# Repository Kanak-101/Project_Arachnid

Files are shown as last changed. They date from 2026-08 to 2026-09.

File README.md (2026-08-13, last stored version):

In development Phase

# Setting up your Laptop (Windows 11)

First connect the bot with your laptop via ethernet.

1. Open PowerShell in administrative mode and run `Get-NetAdapter` to list the connections.
2. Find the one that's your bot's Ethernet. Replace `Ethernet` with your Ethernet name in the following commands. And then run this commands:
```
Remove-NetIPAddress -InterfaceAlias "Ethernet" -Confirm:$false
New-NetIPAddress -InterfaceAlias "Ethernet" -IPAddress 192.168.10.2 -PrefixLength 24
Set-DNsCLientServerAddress -InterfaceAlias "Ethernet" -ResetServerAddresses
```
3. Check if the connection is successfully established by runnig this in powershell `ping 192.168.10.2`
4. Run the `laptop_server.py` python file and open `localhost:5000`

# Setting up the Raspberry Pi 4B for the Bot
The RPi should have Raspberry Pi OS Trixie

1. Clone the repo and go into RPi folder.
```
git clone "https://github.com/Kanak-101/Project_Arachnid"
cd Project_Arachnid/RPI
```
2. Run `make` and your environment will be set up.
3. To run the script `python3 rpi_node.py`

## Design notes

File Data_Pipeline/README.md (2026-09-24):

In development Phase

# 1. Setting up your Laptop 

Connect the bot with your laptop via ethernet.

## Windows 11

1. Open PowerShell in administrative mode and run `Get-NetAdapter` to list the connections.
2. Find the one that's your bot's Ethernet. Replace `Ethernet` with your Ethernet name in the following commands. And then run this commands:
```
Remove-NetIPAddress -InterfaceAlias "Ethernet" -Confirm:$false
New-NetIPAddress -InterfaceAlias "Ethernet" -IPAddress 192.168.10.2 -PrefixLength 24
Set-DNsCLientServerAddress -InterfaceAlias "Ethernet" -ResetServerAddresses
```
3. Check if the connection is successfully established by runnig this in powershell `ping 192.168.10.2`

## Linux

Connect the bot with your laptop via ethernet.

1. Open a terminal and identify your Ethernet interface name (e.g., `eth0` or `enp3s0`) by running `ip link`.
2. Assign the required static IP address to your laptop. Using NetworkManager, which is the same tool the Raspberry Pi setup uses, run the following commands (replace `<interface>` with your actual interface name):  
    * `sudo nmcli connection add con-name "bot-link" ifname <interface> type ethernet ipv4.addresses 192.168.10.2/24 ipv4.method manual`
    * `sudo nmcli connection up "bot-link"`
3. Verify the connection is active by pinging the Raspberry Pi with `ping 192.168.10.1`.  

## Installing python dependencies

Now that connection is successfully established, we will setup an virtual environment for python, install the requirements and run the script.

1. Install pip:
    * Windows: Download the official installer from Python.org. Crucial: Check the box that says "Add python.exe to PATH" before clicking install.
    * Linux: `sudo pacman -S python3 python3-pip python3-venv` or `sudo apt install python3 python3-pip python3-venv`.
2. Navigate to the folder `Project_Arachnid/Data_Pipeline/Laptop`.
3. Create the virtual environment `python -m venv .venv`.
4. Activate virtual environment
    * Windows: Command prompt - `.venv/Scripts/activate.bat`, Powershell - `.venv\Scripts\Activate.ps1`
    * Linux: `source .venv/bin/activate`.
5. Installing dependencies: `pip install -r requirements.txt`.
6. To Deactivate when done run `deactivate`. 
7. Run `python3 laptop_server.py` and navigate to `localhost:5000` in your browser.

**Now your laptop is all set.**

# 2. Setting up Raspberry Pi 5 for the Bot
The RPi should have Raspberry Pi OS Trixie

1. Clone the repo and go into RPi folder.
```
git clone "https://github.com/Kanak-101/Project_Arachnid"
cd Project_Arachnid/Data_Pipeline/RPi
```
2. Run `make` and your environment will be set up.
3. To run the script `python3 rpi_node.py`

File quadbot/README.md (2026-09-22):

# quadbot: bench console, servo calibration, drive, lidar

Milestone 1 of the quadruped build. Runs on the Raspberry Pi 5; you open the dashboard from a
laptop or phone on the same network. Everything works in **mock mode** on any computer, so you can
develop and rehearse without the robot.

## What is in this drop

| Piece | Where | State |
|---|---|---|
| Servo calibration dashboard (per-servo jog, centre/low/high, invert, scale, sweep, save) | `web/`, `quadbot/robot.py` | tested in mock mode |
| Safety: arm, per-servo enable, e-stop latch, command watchdog, ramped jogs, speed/range limiting | `quadbot/robot.py`, `servos.py` | tested in mock mode |
| Leg kinematics + foot-position test tab | `kinematics.py` | tested (round-trip) |
| Crawl / trot / stand / rest gaits + turning | `gait.py` | tested in simulation |
| Auto-slow: gait slows when a servo can't keep up | `servos.py` | tested in simulation |
| Joystick (gamepad, touch sticks, keyboard) | `web/app.js` | tested with keyboard; gamepad code untested |
| Lidar radar view, obstacle stop / slow / steer-around | `lidar.py`, `avoid.py` | avoidance tested; RPLidar driver **untested on hardware** |
| PCA9685 servo driver | `hal.py` | register writes tested against a fake bus; **untested on hardware** |

Not in this drop (next): click-to-go, person tracking, CPG.

## Run it on a laptop (mock)

    python3 -m venv .venv && source .venv/bin/activate
    pip install -r requirements.txt
    python -m quadbot.server              # then open http://localhost:8000
    pytest                                # 52 tests

## Bring-up on the Pi 5

1. `sudo raspi-config` -> Interface Options -> I2C -> enable. Reboot. `sudo apt install i2c-tools`.
   - **Dual PCA9685 boards:** On the Left PCA9685 board, set address to `0x50` (bridge the **A4** address solder pads: 0x40 + 0x10 = 0x50). Leave the Right PCA9685 board unmodified (default address `0x40`).
   - Wire both boards in parallel to the Pi 5's I2C pins: SDA (pin 3), SCL (pin 5), 3.3V logic (pin 1), and GND (pin 6/9).
2. `pip install -r requirements-pi.txt` (inside a venv).
   - Add your user to the `i2c` and `dialout` groups so you can access the I2C bus and lidar without sudo:
     ```bash
     sudo usermod -aG i2c,dialout $USER
     ```
   - Log out and log back in (or run `newgrp i2c`) so the new group permissions apply.
3. **Power & Preventing Servo Jitter:**
   - **Common Ground:** Tie the external servo power supply ground (`GND`) to the Raspberry Pi `GND` (Pin 6). A floating ground reference causes violent servo jitter/twitching.
   - **Current Capacity:** 12 MG958 / MG996R / MG995 servos draw 10A–15A peak. If voltage drops below ~4.5V, servo microcontrollers reset continuously (chatter/buzzing). Use a dedicated 8A–15A 5V–6V battery/BEC.
   - **Logic VCC:** Connect PCA9685 `VCC` to Pi 3.3V (Pin 1). Connect servo power (5V–6V) only to the `V+` screw terminals.
4. **Hardware Diagnostic & Direct Leg Testing:**
   Before launching the web server, test individual legs or servos without tripping power brownouts:
   ```bash
   # Direct leg tester (uses exact pulse limits from Servo Calibration v2):
   python test_legs.py --leg FL             # Test Front-Left leg walking cycle (~0.9A draw)
   python test_legs.py --leg FR             # Test Front-Right leg
   python test_legs.py --leg RL             # Test Rear-Left leg
   python test_legs.py --leg RR             # Test Rear-Right leg
   python test_legs.py --all-seq            # Test all 4 legs sequentially (one by one)
   python test_legs.py --joint FL_femur     # Jog test a single joint
   python test_legs.py                      # Interactive menu

   # Or use the built-in module diagnostic:
   python -m quadbot.diag
   ```
5. `python -m quadbot.server --host 0.0.0.0`, then open `http://<pi-address>:8000`.
   To start on boot use `deploy/quadbot.service`.

There is no login. Anyone on the network can drive the robot. Use your own router or hotspot.

## First-power checklist (do this in order)

1. Robot propped so every leg hangs free. Servo supply off. Start the dashboard.
2. Servo supply on. Press **Arm servos**, then go to **Calibrate**. Nothing moves yet: a servo is only driven once you press its Enable.
3. One servo at a time: **Enable**, then jog with the ±1 / ±10 buttons. The slider ramps at a limited speed, so a drag cannot slam the horn into a stop.
4. **Set centre** at the calibration pose: coxa straight out from the body, femur level, tibia vertical.
5. Jog toward each end. **Set low** and **Set high** a little before the mechanical stop.
6. Watch the **Pose map**. If the drawn leg moves the opposite way to the real one, press **Invert**. Expect several right-side servos to need it.
7. **Calibrate scale**: jog to an angle you can measure, enter it, press the button. The default assumes about 180 degrees across the pulse range, which is only a guess.
8. **Sweep test** shows the servo's whole calibrated range slowly. Listen for buzzing or stalling at the ends and tighten the limits if you hear it.
9. **Save config**. The old file is kept as `robot.yaml.bak`.
10. **Legs** tab: measure your leg segments, put the real coxa / femur / tibia lengths and hip positions into `robot.yaml`, then use the foot-position test to check each leg before any walking.
11. Only then: **Drive**, **Stand**, then **Crawl** with the body held off the ground.

## How the pieces fit

    dashboard (browser)  --websocket-->  server.py  -->  robot.py (50 Hz control tick)
                                                            |-- gait.py         drive command -> foot targets
                                                            |-- kinematics.py   foot targets -> joint angles
                                                            |-- servos.py       limits, speed cap, auto-slow, angle -> pulse
                                                            `-- hal.py          pulse -> PCA9685 (or mock)
    lidar.py --scan--> avoid.py --adjusted drive command--> gait.py

- **Angles** are measured from the calibration pose. Coxa + swings the leg forward, femur + lifts it, tibia + opens the knee. The **Invert** flag maps that to the physical servo direction.
- **Auto-slow:** if a joint can't keep up with its rated speed (or hits its range), the gait rate drops until it can. The **What is holding the gait back** panel shows which joint is responsible.
- **Watchdog:** the dashboard sends the drive command every 50 ms. If none arrive for 0.4 s the robot stops. A stale lidar scan stops forward motion while avoidance is on.
- The CPG plugs in later at `gait.py`, by supplying phase and per-leg offsets in place of the fixed ones.

## Known limits, stated plainly

- **Unverified numbers:** leg lengths, hip positions, servo scale, max speeds, and channel order are placeholders (see comments in `robot.yaml`). Channels are assumed to be 0 to 11 in the order of your calibration sheet.
- **The first pulse after enabling a servo can snap it** to that position at full servo speed, because a servo's real position is unknown until it is driven. Enable one servo at a time, with the legs free.
- The crawl and trot are open-loop kinematic gaits with no balance control. Expect to tune step height, body height, and step rate on the real robot.
- The lidar assumes it sits level. When the body tilts, scans hit the floor. Keep the floor flat until tilt gating is added.
- The layout was checked in a headless DOM test, not on a real screen or phone.

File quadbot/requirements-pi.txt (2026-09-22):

-r requirements.txt
smbus2>=0.4              # PCA9685 servo board over I2C
rplidar-roboticia>=0.9.5 # Slamtec RPLidar

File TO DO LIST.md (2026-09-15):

### TO DO LIST

1\. Modify the legs to fit bearings

2\. Extend the tibia

3\. Screws for the bottom switch holder

4\. hybrid power design

5\. head design with gimbal

6\. Modify the design to fit jetson

7\. Redesign head

8\. improve dashboard UI

### SOFTWARE

1\. Sensor readings

2\. THREAT DETECTION MODEL

3\. make a controller and improve UI

4\. Adaptive environmental movement

5\. Gait mechanics

6\. Mapping

PARTS LIST

1\. battery (x2) - https://robu.in/product/orange-5200mah-1s-25c-3-7-v-lithium-polymer-battery-pack-li-po/

2\. Pi5 cam cable - https://robu.in/product/official-raspberry-pi-5-camera-fpc-cable-500mm/

3\. 65W pd - https://robu.in/product/pd65w-fast-charging-adapter-module-standard-board/

4\. logic level shifter (x5) - https://robu.in/product/smartelex-logic-level-converter-bi-directional/

5\. IMX219 cam for nano - https://thinkrobotics.com/products/imx219-160-camera-with-160-fov-for-jetson-nano-online

6\. ribbon cable for IMX219 - https://probots.co.in/ribbon-flexible-flat-csi-cable-for-raspberry-pi-camera-15-pin-50-cm.html

7\. 1.6x10mm screws (x100) - https://sharvielectronics.com/product/m1-6x10mm-ss-phillips-pan-head-screws-bolt/

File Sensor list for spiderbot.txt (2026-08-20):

GAS SENSORS
MQ2, - LPG, propane, hydrogen, smoke
4, - Methane, Natural gas
5, - LPG, propane
6, - LPG, Butane (more accurate lpg sensor)
7, - Carbon monoxide sensor
8  - hydrogen sensor

to use 4,7,2

LiDAR - Light detection and Ranging ---> Pulsed laser light to measure distances and create precise, 3D representation of everything
MPU6050 - Gyroscope
DHT11 - Temperature and humidity sensor
GPIOS - General purpose input output

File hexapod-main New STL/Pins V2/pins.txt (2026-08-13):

femur2-legrib -4 piece
leg connector adapter pin - 4 piece
frame leg connector - 2 
2 mm pin 4
servo connector pin - 12
coxaside1 wire adapter connector-3
servo horn connector -12

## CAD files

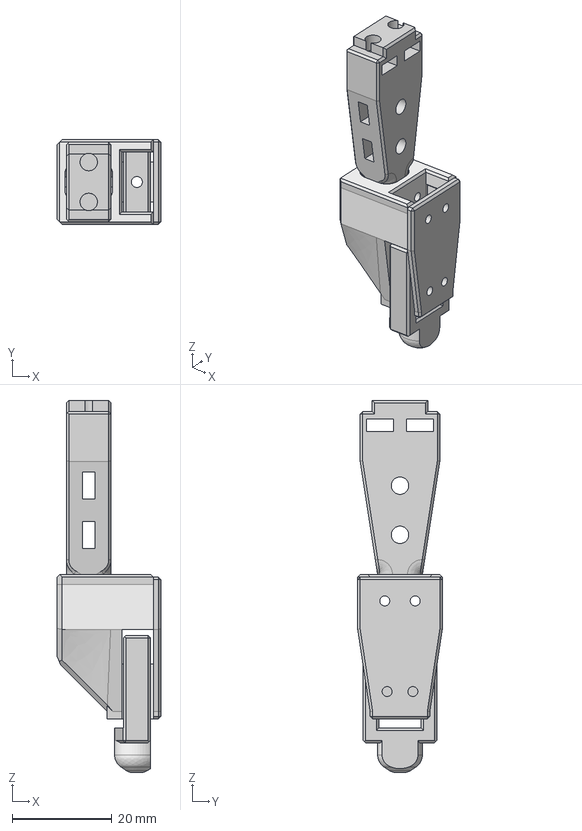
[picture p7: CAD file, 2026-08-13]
hexapod-main New STL/STEP/FootAssembly.step
20.8 x 17.0 x 74.7 mm
micro-switch-holder
TibiaBottom
SwitchCover
tip

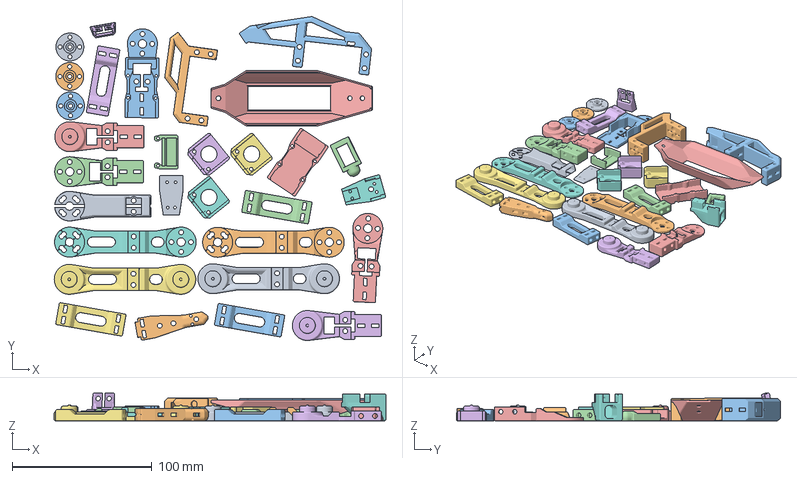
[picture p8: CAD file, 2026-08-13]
Printing_Assembly/Side Leg Assembly with Frame.3mf
237.6 x 232.2 x 19.9 mm
25TServoHorn.stl x 3
CoxaSide1.stl x 2
CoxaSide2.stl x 2
CoxaWireChannelTop.stl
FemurSide1.stl x 2
FemurSide2.stl x 2
FemurWireChannel.stl
FrameSideServoHolder.stl
LegConnectorAdapterBottom v8.stl
LegConnectorAdapterMiddle v2.stl
LegConnectorAdapterTop v1.stl
LegRib v4.stl x 4
micro-switch-holder v10.stl
SwitchCover v3.stl
TibiaBottom v8.stl
TibiaTop v9.stl
tip v8.stl
LegShield.stl
servo-back-hole v9.stl x 3

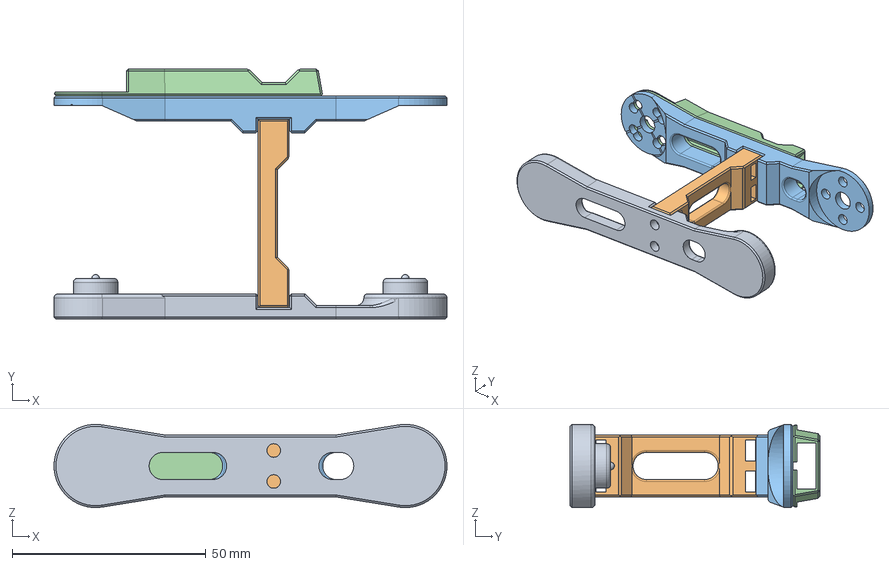
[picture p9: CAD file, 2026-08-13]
hexapod-main New STL/STEP/FemurAssembly.step
101.5 x 64.6 x 21.5 mm
FemurSide1
LegRib
FemurSide2
FemurWireChannel

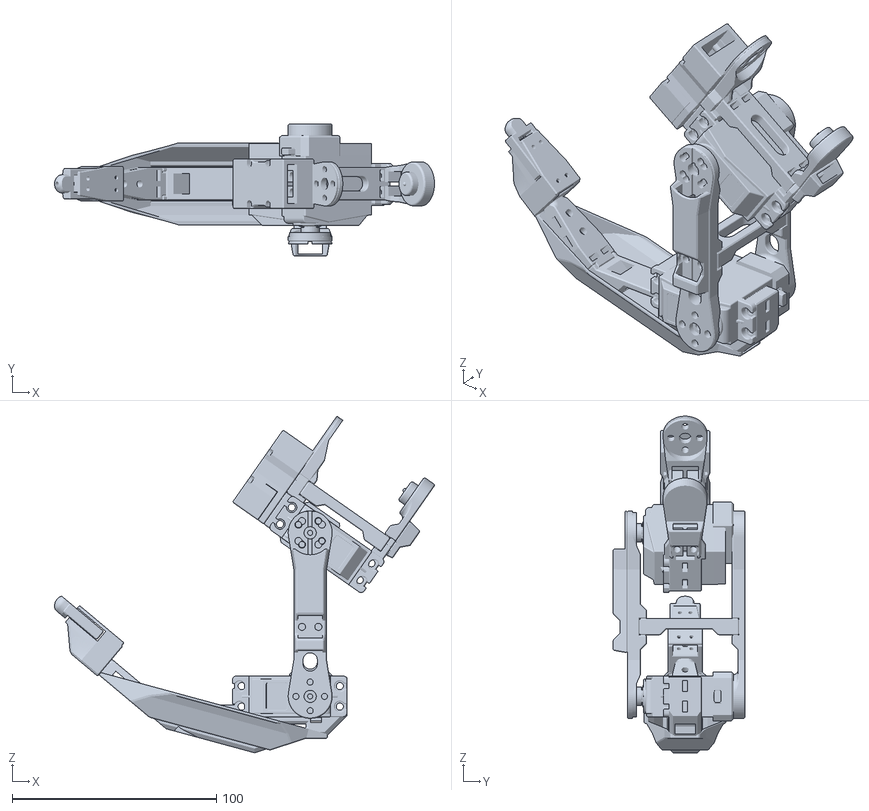
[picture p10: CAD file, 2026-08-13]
hexapod-main New STL/STL/RightLegAssembly v14.stl
185.8 x 64.6 x 164.7

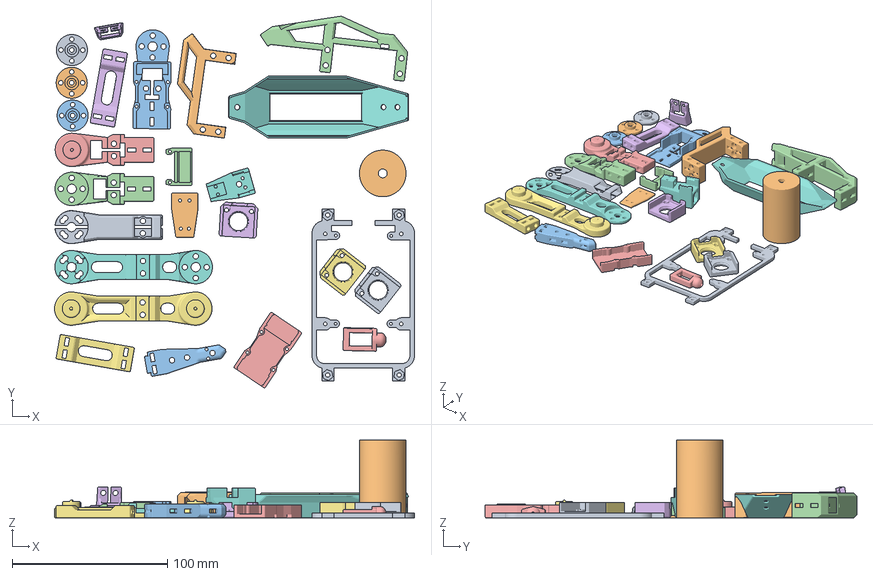
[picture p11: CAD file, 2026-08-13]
Printing_Assembly/SIde Leg Assembly with Controller Frame.3mf
231.9 x 239.5 x 50.0 mm
25TServoHorn.stl x 3
CoxaSide1.stl
CoxaSide2.stl
CoxaWireChannelTop.stl
FemurSide1.stl
FemurSide2.stl
FemurWireChannel.stl
FrameSideServoHolder.stl
LegConnectorAdapterBottom v8.stl
LegConnectorAdapterMiddle v2.stl
LegConnectorAdapterTop v1.stl
LegRib v4.stl x 2
micro-switch-holder v10.stl
servo-back-hole v8.stl x 3
SwitchCover v3.stl
TibiaBottom v8.stl
TibiaTop v9.stl
tip v8.stl
LegShield.stl
ControllerPlate.stl
StandLeg.stl

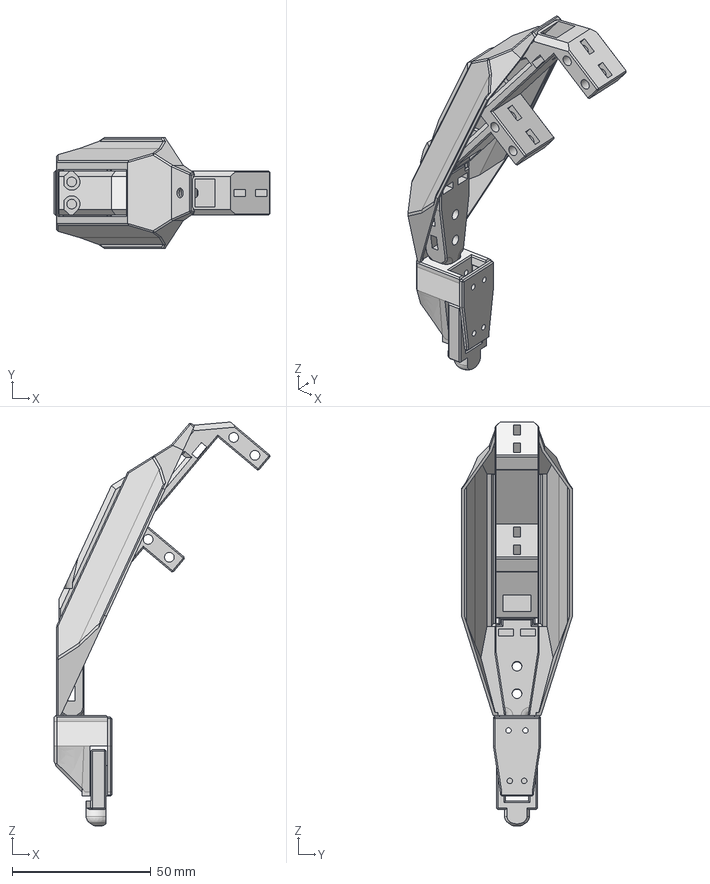
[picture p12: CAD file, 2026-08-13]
hexapod-main New STL/STEP/TibiaAndFootAssembly.step
77.8 x 40.0 x 145.7 mm
TibiaTop
micro-switch-holder
TibiaBottom
SwitchCover
tip
ShieldV2

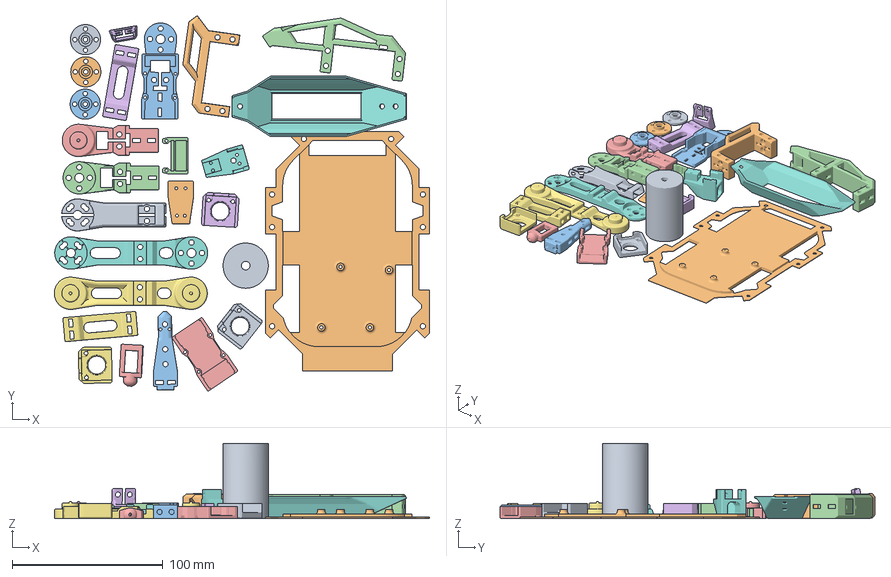
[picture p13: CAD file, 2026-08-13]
Printing_Assembly/Side Leg Assembly with Base Plate.3mf
249.0 x 248.8 x 50.0 mm
25TServoHorn.stl x 3
CoxaSide1.stl
CoxaSide2.stl
CoxaWireChannelTop.stl
FemurSide1.stl
FemurSide2.stl
FemurWireChannel.stl
FrameSideServoHolder.stl
LegConnectorAdapterBottom v8.stl
LegConnectorAdapterMiddle v2.stl
LegConnectorAdapterTop v1.stl
LegRib v4.stl x 2
micro-switch-holder v10.stl
servo-back-hole v8.stl x 3
SwitchCover v3.stl
TibiaBottom v8.stl
TibiaTop v9.stl
tip v8.stl
LegShield.stl
StandLeg.stl
ElectronicsPlate.stl

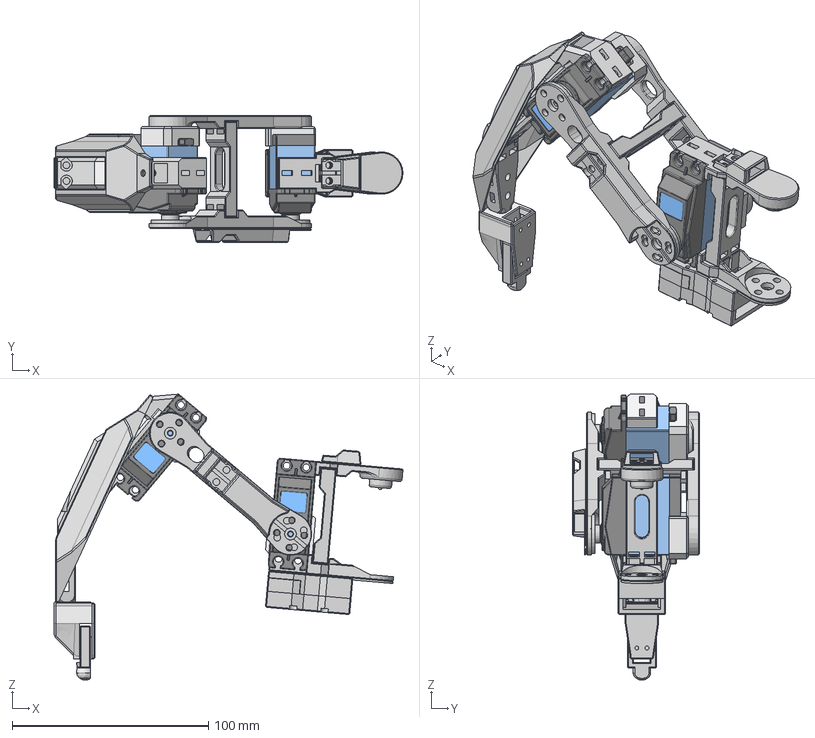
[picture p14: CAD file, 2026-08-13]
hexapod-main New STL/STEP/LeftLegAssembly.step
177.9 x 64.6 x 145.7 mm
pan_head_phillip_mc_screw_m2 v3 (1) x 2
25TServoHorn x 2
LegRib x 2
CoxaSide1
CoxaSide2
CoxaWireChannelTop
LegConnectorAdapterTop
LegConnectorAdapterBottom
LegConnectorAdapterMiddle
FemurSide1
FemurSide2
FemurWireChannel
TibiaTop
micro-switch-holder
TibiaBottom
SwitchCover
tip
ShieldV2

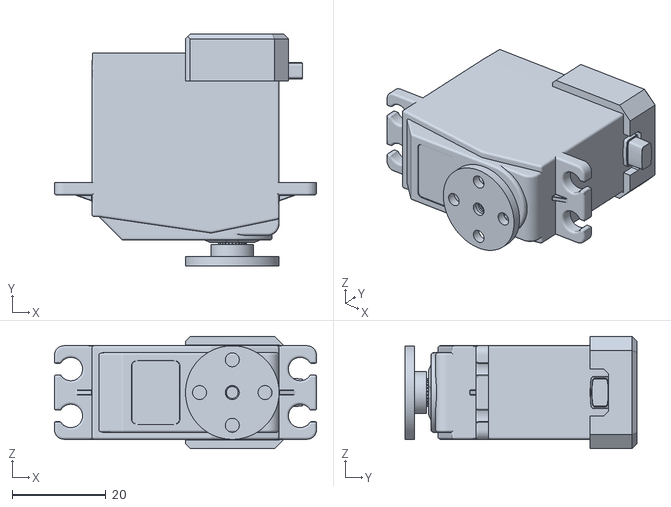
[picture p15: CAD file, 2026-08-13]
hexapod-main New STL/STL/ServoAssembly v8.stl
56.0 x 49.5 x 24.0

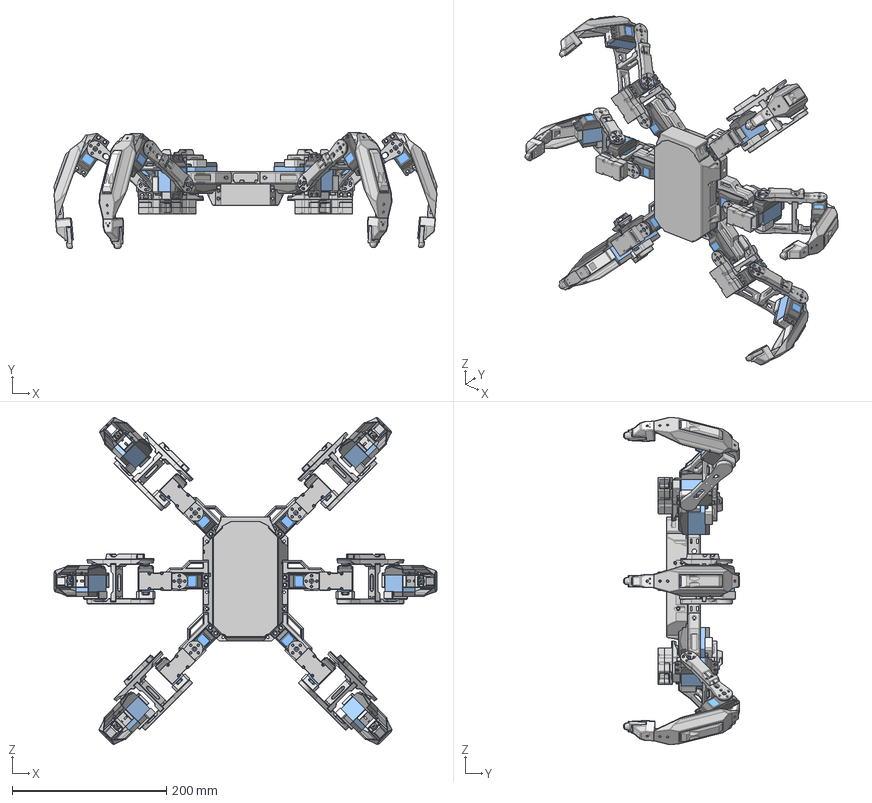
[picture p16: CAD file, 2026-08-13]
hexapod-main New STL/STEP/FrameAssembly.step
495.9 x 150.8 x 423.6 mm
FrameCenterServoHolder
FrameV2
FrameCenterServoHolder v4(Mirror)
FrameSideServoHolder x 2
FrameSideServoHolder v3(Mirror)
FrameSideServoHolder v3(Mirror) (1)
ElectronicsPlate
PowerCompartment
PowerCompartmentDoor
pan_head_phillip_mc_screw_m2 v3 (1) x 18
25TServoHorn x 18
LegRib x 12
CoxaSide1 x 6
CoxaSide2 x 6
CoxaWireChannelTop x 6
LegConnectorAdapterTop x 6
LegConnectorAdapterBottom x 6
LegConnectorAdapterMiddle x 6
FemurSide1 x 6
FemurSide2 x 6
FemurWireChannel x 6
TibiaTop x 6
micro-switch-holder x 6
TibiaBottom x 6
SwitchCover x 6
tip x 6
ShieldV2 x 6
CurrentVoltageSensorAndServoDriverBuck

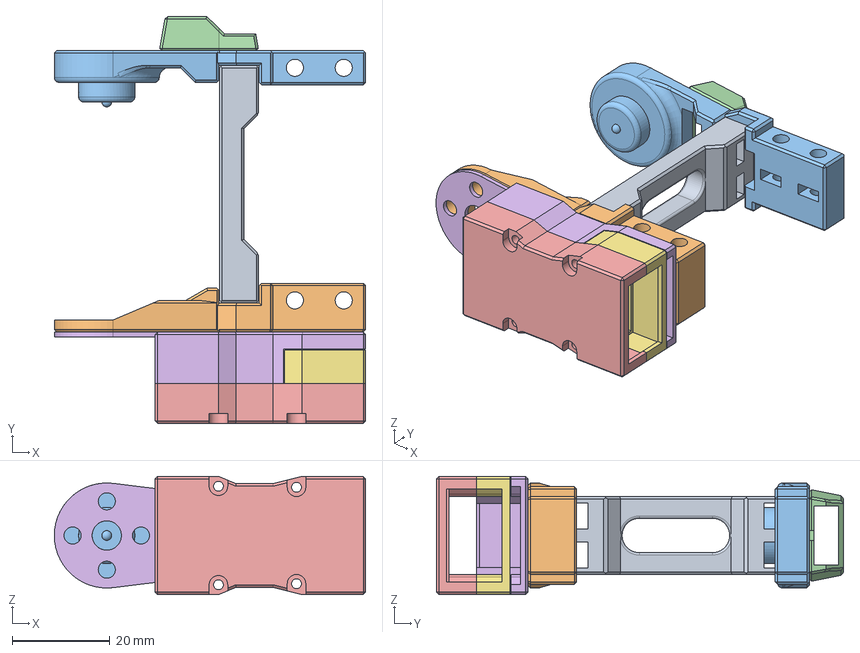
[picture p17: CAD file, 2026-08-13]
hexapod-main New STL/STEP/CoxaAssembly.step
63.8 x 83.3 x 24.2 mm
LegRib
CoxaSide1
CoxaSide2
CoxaWireChannelTop
LegConnectorAdapterTop
LegConnectorAdapterBottom
LegConnectorAdapterMiddle

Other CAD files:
hexapod-main New STL/STL/FootAssembly v11.stl
hexapod-main New STL/STL/TibiaAndFootAssembly v7.stl
hexapod-main New STL/STL/LeftLegAssembly v14.stl
hexapod-main New STL/STEP/RightLegAssembly.step
hexapod-main New STL/STL/FemurAssembly v13.stl
hexapod-main New STL/STL/CoxaAssembly v23.stl
hexapod-main New STL/STEP/ServoAssembly.step
Bot_upper_structure_fusion/ElectronicsPlate.f3d
Bot_upper_structure_fusion/Gimbal_Camera_Mount.f3d
Bot_upper_structure_fusion/Gimbal_Main_Base.f3d
Bot_upper_structure_fusion/Gimbal_Tilt_Mount.f3d
Bot_upper_structure_fusion/_SG90+9g+Micro+Servo.e43d2cae-f814-41ba-8a0c-7b5be9030956.f3d
Bot_upper_structure_fusion/gimbal assembly.f3z
Bot_upper_structure_fusion/upper case spider bot.f3d
Printing_Assembly/All Pins.3mf
hexapod-main New STL/Fusion/CoxaAssembly v23.f3z
hexapod-main New STL/Fusion/FemurAssembly v13.f3z
hexapod-main New STL/Fusion/FootAssembly v11.f3z
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

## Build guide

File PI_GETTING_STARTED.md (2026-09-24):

# 🕷️ Complete Raspberry Pi Getting Started Guide — Nav2 & SLAM

This guide walks you through every single step to get RPLidar, Cartographer, and Nav2 autonomously driving your quadbot on your Raspberry Pi.

---

## 📋 Architecture & Data Flow

```text
[RPLidar USB] 
      │
      ▼
[/scan topic] ───► [Cartographer Node] ──► publishes [map → odom TF] & [/map]
      │                     ▲
      ▼                     │
[Nav2 Costmaps] ────────────┘
      │
      ▼ (Global/Local Planners)
[/cmd_vel] ──► [cmd_vel_bridge node] ──(WebSocket ws://127.0.0.1:8000/ws)──► [quadbot.server] ──► [PCA9685 Servos]
```

---

## ⚡ Step 1: Connect to Pi & Pull Changes

Open PowerShell or terminal on your laptop:

```bash
# 1. SSH into the Pi
ssh <your_pi_username>@<your_pi_ip>

# 2. Go to your repo folder
cd ~/Project_Arachnid
# (or wherever your repo directory is located on your Pi)

# 3. Discard or stash any local conflict files if needed
git stash

# 4. Pull latest commit from main
git pull origin main
```

---

## 📦 Step 2: Install System & ROS 2 Dependencies

Nav2 and Cartographer need native binaries. Run this once on the Pi:

```bash
sudo apt update
sudo apt install -y \
  ros-${ROS_DISTRO}-navigation2 \
  ros-${ROS_DISTRO}-nav2-bringup \
  ros-${ROS_DISTRO}-cartographer \
  ros-${ROS_DISTRO}-cartographer-ros \
  ros-${ROS_DISTRO}-tf2-ros \
  ros-${ROS_DISTRO}-rplidar-ros \
  python3-websockets
```

> [!NOTE]
> If your environment does not have `$ROS_DISTRO` set, check which ROS 2 version you have (usually `humble` or `jazzy`). Replace `${ROS_DISTRO}` with `humble` or `jazzy`.

---

## 🔌 Step 3: Check Hardware & USB Permissions

### 1. Give RPLidar USB permissions
When plugging in RPLidar to Pi USB port:
```bash
ls -l /dev/ttyUSB*
```
You should see `/dev/ttyUSB0`. Give it read/write permissions:
```bash
sudo chmod 666 /dev/ttyUSB0
```
*(To make this permanent across reboots, add your user to dialout: `sudo usermod -a -G dialout $USER` and log back in).*

### 2. Verify I2C is working (PCA9685 & MPU6050)
```bash
sudo i2cdetect -y 1
```
You should see your PCA9685 addresses (`0x40`, `0x50`) and optionally MPU6050 (`0x68`).

---

## 🛠️ Step 4: Build the ROS 2 Workspace

From the root of your workspace on the Pi:

```bash
cd ~/Project_Arachnid

# Clean previous build artifacts if needed
rm -rf build/quadbot_nav2 install/quadbot_nav2

# Build all 3 core packages
colcon build --packages-select quadbot_cartographer cmd_vel_bridge quadbot_nav2 --symlink-install

# Source the overlay
source install/setup.bash
```

Ensure it finishes without errors. Add sourcing to your `~/.bashrc` so every new terminal has it:
```bash
echo "source ~/Project_Arachnid/install/setup.bash" >> ~/.bashrc
```

---

## 🚀 Step 5: Running the System (Multi-Terminal Workflow)

To avoid everything crashing together, run each core component in its own terminal (or use `tmux`).

### Terminal 1: Start Quadbot Hardware Server
This drives the PCA9685 servos and listens on WebSocket port 8000:
```bash
cd ~/Project_Arachnid
source install/setup.bash
python3 -m quadbot.server --config quadbot/config/robot.yaml --host 0.0.0.0
```
- Open `http://<pi_ip>:8000` in your laptop browser to see the dashboard.
- **Arm the robot and put it in `stand` or `crawl` mode** so it responds to drive commands.

---

### Terminal 2: Launch RPLidar Node (if not already running inside server)
If you are streaming scan into ROS 2 directly via `rplidar_ros`:
```bash
source /opt/ros/${ROS_DISTRO}/setup.bash
ros2 run rplidar_ros rplidar_node --ros-args \
  -p serial_port:=/dev/ttyUSB0 \
  -p serial_baudrate:=115200 \
  -p frame_id:=laser \
  -p angle_compensate:=true
```

Test that the scan is publishing:
```bash
ros2 topic hz /scan
# Should output: average rate: ~5.5Hz - 10Hz
```

---

### Terminal 3: Launch Nav2 + Cartographer SLAM + Bridge
This starts:
1. Static TF (`base_link -> laser`)
2. `cartographer_node` + `occupancy_grid_node` (publishes `/map` and `map -> odom`)
3. `cmd_vel_bridge` (listens on `/cmd_vel` -> sends WebSocket drive packet to `quadbot.server`)
4. Full Nav2 stack (planner, controller, BT navigator, costmaps)

```bash
cd ~/Project_Arachnid
source install/setup.bash
ros2 launch quadbot_nav2 quadbot_nav2_slam.launch.py
```

Check lifecycle status:
```bash
ros2 lifecycle list /controller_server
# Should show [active]
```

---

## 💻 Step 6: Visualizing & Driving with RViz2 (From your Laptop)

Do **NOT** run RViz2 on the Pi directly (it will overheat or lag the Pi CPU/GPU). Run RViz2 on your laptop.

### 1. Ensure both Laptop and Pi are on the same Wi-Fi
Set the same `ROS_DOMAIN_ID` on both Pi and Laptop:
```bash
# In Pi ~/.bashrc and Laptop terminal:
export ROS_DOMAIN_ID=0
```

### 2. On your Laptop:
```bash
cd ~/Project_Arachnid
source install/setup.bash
ros2 launch quadbot_nav2 rviz.launch.py
```

### 3. Send Goals:
1. In RViz2, you will see the red laser points and the gray occupancy grid building as the robot moves.
2. Click **"2D Nav Goal"** (or **"Nav2 Goal"**) on the RViz top toolbar.
3. Click and drag anywhere on the map to set a goal position and heading direction.
4. Watch Nav2 generate a green path, plan speed commands on `/cmd_vel`, which bridge to your quadbot server!

---

## 💾 Step 7: Saving Your Map for Future Pure Navigation

Once you've explored the room and built a complete map:

On the Pi (or laptop):
```bash
ros2 run nav2_map_server map_saver_cli -f ~/Project_Arachnid/src/quadbot_nav2/maps/my_room
```
This generates:
- `my_room.yaml`
- `my_room.pgm`

### Navigating on the Saved Map Later (without running SLAM):
```bash
ros2 launch quadbot_nav2 quadbot_nav2_localization.launch.py map:=$HOME/Project_Arachnid/src/quadbot_nav2/maps/my_room.yaml
```
In RViz, use **"2D Pose Estimate"** first to tell AMCL where the robot started, then click **"2D Nav Goal"**.

---

## 🔧 Troubleshooting Quick-Fixes

| Issue | Cause | Fix |
|---|---|---|
| `cmd_vel_bridge: Quadbot websocket unavailable` | `quadbot.server` isn't running or wrong port | Start `python3 -m quadbot.server` first in Terminal 1. |
| `Waiting for transform map -> odom` | Cartographer hasn't received scan or crashed | Verify `ros2 topic echo /scan --once`. Ensure frame is `laser`. |
| Robot doesn't move when goal is given | Robot not armed in dashboard | Go to `http://<pi_ip>:8000`, click **Arm**, and set mode to **crawl** or **trot**. |
| DWB planner error: Extrapolation into future | Time sync between laptop & Pi | Install `chrony` or sync clocks with `sudo date -s "..."`. |

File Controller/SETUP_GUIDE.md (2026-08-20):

# Project Arachnid — Complete Setup & Deployment Guide

---

## 1. File Overview

```
arachnid/
├── rpi/
│   ├── servo_driver.py        ← PCA9685 low-level servo interface
│   ├── gait_engine.py         ← Tripod gait + IK + single-leg control
│   ├── sensor_node.py         ← All sensors in parallel threads
│   ├── arachnid_server.py     ← TCP server (MAIN ENTRY POINT on RPi)
│   ├── arachnid_sensors.ino   ← Arduino sketch (upload to Uno)
│   ├── setup_static_ip.sh     ← One-time network config script
│   └── arachnid.service       ← systemd auto-start service
└── laptop/
    └── arachnid_controller.py ← Keyboard controller (run on your laptop/WSL)
```

---

## 2. Hardware Wiring

### PCA9685 Boards (I2C)
Connect both boards to RPi I2C pins:
```
RPi Pin 3  (GPIO2, SDA)  → SDA on BOTH boards
RPi Pin 5  (GPIO3, SCL)  → SCL on BOTH boards
RPi Pin 6  (GND)         → GND on both boards
RPi Pin 2  (5V)          → VCC on both boards (logic only)
External 5V/6V supply    → V+ on both boards (servo power — DO NOT use RPi 5V)
```

Board address jumpers:
- Board A (Legs 1–3): A0=LOW, A1=LOW → address 0x40 (default, no solder)
- Board B (Legs 4–6): A0=HIGH, A1=LOW → address 0x41 (bridge A0 solder jumper)

Servo channel assignment per board:
```
Board A (0x40):        Board B (0x41):
  Ch 0 → Leg 1 J1 (Coxa)    Ch 0 → Leg 4 J1
  Ch 1 → Leg 1 J2 (Femur)   Ch 1 → Leg 4 J2
  Ch 2 → Leg 1 J3 (Tibia)   Ch 2 → Leg 4 J3
  Ch 3 → Leg 2 J1            Ch 3 → Leg 5 J1
  Ch 4 → Leg 2 J2            Ch 4 → Leg 5 J2
  Ch 5 → Leg 2 J3            Ch 5 → Leg 5 J3
  Ch 6 → Leg 3 J1            Ch 6 → Leg 6 J1
  Ch 7 → Leg 3 J2            Ch 7 → Leg 6 J2
  Ch 8 → Leg 3 J3            Ch 8 → Leg 6 J3
```

Leg numbering (top view, X = forward):
```
    L6 ──── L1
    L5        L2
    L4 ──── L3
```

### Arduino Uno (Sensors)
```
MQ-2  → A0       MQ-4  → A1       MQ-5  → A2
MQ-6  → A3       MQ-7  → A4       MQ-8  → A5
HC-SR04 FRONT:  TRIG=D2, ECHO=D3
HC-SR04 LEFT:   TRIG=D4, ECHO=D5
HC-SR04 RIGHT:  TRIG=D6, ECHO=D7
Arduino USB     → RPi USB port (appears as /dev/ttyUSB0)
```

### DHT11
```
DHT11 DATA → RPi GPIO 4 (Pin 7)
DHT11 VCC  → RPi 3.3V
DHT11 GND  → RPi GND
```

### MPU6050 IMU
```
MPU6050 SDA → RPi GPIO 2 (shares I2C bus with PCA9685)
MPU6050 SCL → RPi GPIO 3
MPU6050 VCC → RPi 3.3V
MPU6050 GND → RPi GND
MPU6050 AD0 → GND  (sets I2C address to 0x68)
```

### GPS M8N
```
GPS TX → RPi GPIO 15 (Pin 10, UART RX = /dev/ttyAMA0)
GPS RX → RPi GPIO 14 (Pin 8,  UART TX — optional)
GPS VCC → 3.3V or 5V (check your module)
GPS GND → GND
```
Enable UART on RPi: `sudo raspi-config` → Interface Options → Serial Port
  → "login shell over serial?" → NO
  → "serial port hardware enabled?" → YES

---

## 3. RPi Software Setup

SSH into the RPi (use default: `ssh pi@raspberrypi.local` before static IP).

### Install Python dependencies
```bash
sudo apt update && sudo apt install -y python3-pip libgpiod2 i2c-tools
pip3 install adafruit-circuitpython-pca9685 \
             adafruit-circuitpython-servokit \
             adafruit-circuitpython-dht \
             adafruit-circuitpython-mpu6050 \
             pyserial pynmea2
```

### Enable I2C
```bash
sudo raspi-config
# Interface Options → I2C → Enable
```

Verify boards are detected:
```bash
sudo i2cdetect -y 1
# Should show 0x40 and 0x41 for PCA9685 boards, 0x68 for MPU6050
```

### Upload Arduino sketch
1. Open `arachnid_sensors.ino` in Arduino IDE on your laptop
2. Select Board: Arduino Uno, Port: (your COM port)
3. Upload
4. Transfer the .ino to RPi is NOT needed — it runs on the Uno directly

### Copy project files to RPi
```bash
# From your laptop (WSL or terminal):
scp rpi/*.py pi@192.168.0.100:/home/pi/arachnid/
```

---

## 4. Static IP Setup

### On the RPi
```bash
chmod +x /home/pi/arachnid/setup_static_ip.sh
bash /home/pi/arachnid/setup_static_ip.sh
```
RPi Ethernet is now: **192.168.0.100**

### On your Windows laptop
1. Control Panel → Network and Internet → Network Connections
2. Right-click Ethernet adapter → Properties
3. Select "Internet Protocol Version 4 (TCP/IPv4)" → Properties
4. Set:
   - IP address:    `192.168.0.101`
   - Subnet mask:   `255.255.255.0`
   - Default gateway: (leave blank)
5. OK → Close

### Test the connection
```bash
# From WSL:
ping 192.168.0.100

# From RPi:
ping 192.168.0.101
```

---

## 5. Running the System

### Start the server on RPi
```bash
ssh pi@192.168.0.100
cd /home/pi/arachnid
python3 arachnid_server.py
```
You should see:
```
  Project Arachnid — RPi Server
[boot] Initialising servos...
[servo_driver] PCA9685 boards initialised.
[boot] Starting sensor threads...
[sensor] Started thread: arduino
[sensor] Started thread: dht
...
[server] Listening on 0.0.0.0:5000
```

### Run the controller on your laptop (WSL)
```bash
cd laptop/
pip install windows-curses   # first time only
python3 arachnid_controller.py
```

---

## 6. Auto-start on Boot (optional but recommended)

```bash
# On RPi:
sudo cp /home/pi/arachnid/arachnid.service /etc/systemd/system/
sudo systemctl daemon-reload
sudo systemctl enable arachnid
sudo systemctl start arachnid

# Check status:
sudo systemctl status arachnid
journalctl -u arachnid -f   # live logs
```

---

## 7. Controller Key Bindings

### Mode 1 — Full Body
| Key | Action |
|-----|---|
| W | Forward |
| S | Backward |
| A | Strafe Left |
| D | Strafe Right |
| Q | Turn Left (CCW) |
| E | Turn Right (CW) |
| SPACE | Stand (home pose) |
| N | Neutral (all joints centre) |
| TAB | Switch to Mode 2 |
| ESC | **Emergency Stop** (servos go limp) |
| R | Resume from E-Stop |
| + / - | Increase / Decrease step size |

### Mode 2 — Single Leg
| Key | Action |
|-----|---|
| 1–6 | Select leg (1=Front-R, 2=Right, 3=Back-R, 4=Back-L, 5=Left, 6=Front-L) |
| W / S | Move foot Forward / Backward |
| A / D | Move foot Left / Right |
| Z / X | Move foot Up / Down |
| TAB | Back to Mode 1 |

---

## 8. Tuning the Gait

Edit these values in `gait_engine.py` after your first test:

```python
STEP_LENGTH   = 0.035   # reduce if legs slip or collide
STEP_HEIGHT   = 0.030   # increase if feet drag on ground
BODY_HEIGHT   = 0.080   # adjust to match actual standing height
CYCLE_TIME    = 0.5     # increase (slower) if servos can't keep up
```

---

## 9. Troubleshooting

| Problem | Fix |
|---|-----|
| `OSError: [Errno 121] Remote I/O error` | I2C not enabled, or board address wrong |
| Servos twitch but don't move | Swap PULSE_MIN/MAX values in servo_driver.py |
| Legs move wrong direction | Negate the affected joint angle in set_joint_rad |
| Arduino not found | Check `ls /dev/ttyUSB*`, update port in sensor_node.py |
| GPS no data | Run `sudo raspi-config` and enable serial hardware |
| Controller can't connect | Check IP in arachnid_controller.py matches RPi |
| Servos go limp immediately | Power supply voltage too low — use 5V/6V 5A+ |

---

## 10. Sensor Port Reference

Edit `arachnid_server.py` → `sensor_node.start_all(...)` if your ports differ:

```python
sensor_node.start_all(
    arduino_port = "/dev/ttyUSB0",   # Arduino Uno
    gps_port     = "/dev/ttyAMA0",   # GPS M8N via UART
    dht_pin      = 4,                # DHT11 GPIO pin number
)
```

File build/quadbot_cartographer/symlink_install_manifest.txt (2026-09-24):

/home/leevai/quadbot_ws/install/quadbot_cartographer/share/quadbot_cartographer/launch/quadbot_slam.launch.py
/home/leevai/quadbot_ws/install/quadbot_cartographer/share/quadbot_cartographer/config/quadbot.lua
/home/leevai/quadbot_ws/install/quadbot_cartographer/share/ament_index/resource_index/package_run_dependencies/quadbot_cartographer
/home/leevai/quadbot_ws/install/quadbot_cartographer/share/ament_index/resource_index/parent_prefix_path/quadbot_cartographer
/home/leevai/quadbot_ws/install/quadbot_cartographer/share/quadbot_cartographer/environment/ament_prefix_path.sh
/home/leevai/quadbot_ws/install/quadbot_cartographer/share/quadbot_cartographer/environment/ament_prefix_path.dsv
/home/leevai/quadbot_ws/install/quadbot_cartographer/share/quadbot_cartographer/environment/path.sh
/home/leevai/quadbot_ws/install/quadbot_cartographer/share/quadbot_cartographer/environment/path.dsv
/home/leevai/quadbot_ws/install/quadbot_cartographer/share/quadbot_cartographer/local_setup.bash
/home/leevai/quadbot_ws/install/quadbot_cartographer/share/quadbot_cartographer/local_setup.sh
/home/leevai/quadbot_ws/install/quadbot_cartographer/share/quadbot_cartographer/local_setup.zsh
/home/leevai/quadbot_ws/install/quadbot_cartographer/share/quadbot_cartographer/local_setup.dsv
/home/leevai/quadbot_ws/install/quadbot_cartographer/share/quadbot_cartographer/package.dsv
/home/leevai/quadbot_ws/install/quadbot_cartographer/share/ament_index/resource_index/packages/quadbot_cartographer
/home/leevai/quadbot_ws/install/quadbot_cartographer/share/quadbot_cartographer/cmake/quadbot_cartographerConfig.cmake
/home/leevai/quadbot_ws/install/quadbot_cartographer/share/quadbot_cartographer/cmake/quadbot_cartographerConfig-version.cmake
/home/leevai/quadbot_ws/install/quadbot_cartographer/share/quadbot_cartographer/package.xml

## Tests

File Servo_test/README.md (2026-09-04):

\#You can control the servos by navigating the screen through the buttons. There are two modes in the code, The one opened by default on the screen is designed to check the speed and sweep movement of the servos. 

\#Pressing the 'up', 'down', and 'ok' button together will change the screen output to exact pwm signal at that angle for easier calibration. When in this mode, pressing the 'ok' button will automatically set the servo to 90 degrees.

### 

# **ESP32 PINOUT** 

##### 

###### left button  - 4

###### right button - 25

###### up button    - 32

###### down button  - 15

###### OK button    - 33 

###### 

###### Red\_LED      - 17

###### Green\_\_LED   - 16

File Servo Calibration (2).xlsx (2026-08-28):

S.No | LEG POSITION | JOINT | SERVO MODEL | SRV_MIN | SRV_MAX | SERVO | TYPE | SWEEP ANGLE
1 | Front - Left | Coxa | MG958 | 500 | 2500 | MG958 | Digital | ~180
2 | Front - Left | Femur | MG958 | 620 | 2380 | Mg996R | Analog / Digital | ~180
3 | Front - Left | Tibia | MG958 | 620 | 2380 | MG995 | Analog | ~180
 |  |  |  |  |  | S20F | Digital | ~180
4 | Front - Right | Coxa | MG958 | 500 | 2500 | AS3103 | Analog | ~150-160
5 | Front - Right | Femur | MG996R | 620 | 2380
6 | Front - Right | Tibia | MG996R | 620 | 2380
7 | Rear - Left | Coxa | MG958 | 500 | 2500
8 | Rear - Left | Femur | MG995 | 600 | 2400
9 | Rear - Left | Tibia | MG995 | 600 | 2400
10 | Rear - Right | Coxa | MG958 | 500 | 2500
11 | Rear - Right | Femur | MG996R | 500 | 2500
12 | Rear - Right | Tibia | MG996R | 750 | 2250

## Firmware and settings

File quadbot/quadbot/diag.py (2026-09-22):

"""Standalone hardware diagnostic & bring-up utility for quadbot.

Allows testing gait and motion on INDIVIDUAL SERVOS or SINGLE LEGS,
eliminating high current draw and avoiding power supply brownouts.

Run on the Raspberry Pi:
    python -m quadbot.diag

Run specific single-servo or single-leg gait tests:
    python -m quadbot.diag --gait-servo FL_femur   # Only 1 servo powered!
    python -m quadbot.diag --gait-leg FL          # Only 3 servos powered!
    python -m quadbot.diag --gait-board left      # Only 6 servos powered!
    python -m quadbot.diag --stand-leg FL         # Stand pose on 1 leg
    python -m quadbot.diag --test-servo FL_coxa   # Jog single servo
    python -m quadbot.diag --scan                 # Scan I2C for 0x40 and 0x50
    python -m quadbot.diag --all-1500             # Soft-center all 12
    python -m quadbot.diag --release              # Release all servos
"""
import argparse
import sys
import time
from pathlib import Path

from . import config as cfgmod
from .gait import GaitEngine
from .hal import PCA9685Driver, make_driver
from .kinematics import LegKinematics

ROOT = Path(__file__).resolve().parent.parent


def scan_i2c_bus(bus_num=1):
    """Scan I2C bus and return list of detected addresses in hex."""
    found = []
    try:
        from smbus2 import SMBus
        with SMBus(bus_num) as bus:
            for addr in range(0x03, 0x78):
                try:
                    bus.read_byte(addr)
                    found.append(addr)
                except OSError:
                    pass
    except Exception as e:
        print(f"[!] Could not access /dev/i2c-{bus_num}: {e}")
        return []
    return found


def print_i2c_report(found):
    print("\n" + "=" * 55)
    print("           I2C HARDWARE SCAN REPORT")
    print("=" * 55)
    if not found:
        print("[!] No I2C devices responded on bus 1.")
        print("    Troubleshooting steps:")
        print("    1. ADS1115 Level Shifter: If recently wired, disconnect its SDA & SCL")
        print("       wires from the Pi. A miswired level shifter pulls the entire bus LOW.")
        print("    2. Enable I2C: sudo raspi-config -> Interface Options -> I2C -> Yes")
        print("    3. Check Pi pin 1 (3.3V) -> PCA9685 VCC (both boards)")
        print("    4. Check Pi pin 6 (GND) -> PCA9685 GND (both boards)")
        print("    5. Check Pi pin 3 (SDA) -> PCA9685 SDA (both boards)")
        print("    6. Check Pi pin 5 (SCL) -> PCA9685 SCL (both boards)")
        print("    7. Check Servo V+ power terminal (2S battery / UBEC switch).")
        return False

    print(f"Detected I2C addresses on /dev/i2c-1: {[hex(a) for a in found]}")
    left_ok = 0x50 in found
    right_ok = 0x40 in found
    ads_ok = 0x48 in found

    print(f"  * Left Board  (0x50): {'[OK] Detected' if left_ok else '[FAIL] Missing! (Verify A4 solder jumper)'}")
    print(f"  * Right Board (0x40): {'[OK] Detected' if right_ok else '[FAIL] Missing!'}")
    print(f"  * ADS1115 ADC (0x48): {'[OK] Detected (2S Battery monitor active)' if ads_ok else '[--] Not detected (Battery monitor optional)'}")

    # Unlock PCA9685 boards in case ALL_LED_OFF bit was latched
    try:
        from smbus2 import SMBus
        with SMBus(1) as bus:
            for addr in (0x40, 0x50):
                if addr in found:
                    try:
                        bus.write_byte_data(addr, 0x00, 0x20)  # wake + auto-inc
                        bus.write_byte_data(addr, 0x01, 0x04)  # totem-pole push-pull
                        bus.write_byte_data(addr, 0xFD, 0x00)  # clear ALL_LED_OFF
                        bus.write_byte_data(addr, 0xFB, 0x00)  # clear ALL_LED_ON
                    except Exception:
                        pass
    except Exception:
        pass

    if not left_ok or not right_ok:
        print("\n[!] WARNING: Both boards must be detected for normal operation.")
        if not left_ok:
            print("    -> For Left Board (0x50): Bridge solder pads for A4 on the PCA9685.")
            print("       If your board has address 0x41 (A0 bridged), change address in config/robot.yaml.")
    return left_ok and right_ok


def test_single_servo(driver, servo, duration_s=2.5):
    """Gently jog a single servo back and forth to verify wiring."""
    print(f"\n---> Testing Servo: {servo.id} (Board: {servo.board}, Ch: {servo.channel})")
    center = servo.us_center
    is_coxa = "coxa" in servo.id
    deg_step = 6 if is_coxa else 10
    dwell = 0.6 if is_coxa else 0.4
    print(f"     Jogging: Center -> +{deg_step}° -> -{deg_step}° -> Center (Dwell: {dwell}s) ...")
    step = deg_step * servo.us_per_deg * (1 if not servo.invert else -1)
    
    t0 = time.monotonic()
    try:
        while time.monotonic() - t0 < duration_s:
            driver.set_pulse(servo.channel, center + step, board=servo.board)
            time.sleep(dwell)
            driver.set_pulse(servo.channel, center - step, board=servo.board)
            time.sleep(dwell)
        driver.set_pulse(servo.channel, center, board=servo.board)
        time.sleep(0.2)
    finally:
        driver.release(servo.channel, board=servo.board)
        print(f"     Finished & released {servo.id}.")


def soft_center_all(driver, servos, delay_s=0.15):
    """Enable and center all servos sequentially to avoid power brownouts."""
    print("\n---> Soft-centering all 12 servos to 1500 µs (sequential soft start)...")
    for sid, s in servos.items():
        print(f"     Centering {sid:10s} (board: {s.board}, ch: {s.channel})...")
        driver.set_pulse(s.channel, s.us_center, board=s.board)
        time.sleep(delay_s)
    print("     [OK] All 12 servos centered at 1500 µs.")


def test_stand_pose(driver, cfg, servos, duration_s=4.0, target=None):
    """Calculate and set legs into stand pose using kinematics. Supports single leg/servo targeting."""
    active_sids = set()
    if target in servos:
        active_sids.add(target)
        desc = f"Single Servo '{target}'"
    elif target in ("FL", "FR", "RL", "RR"):
        active_sids.update(f"{target}_{j}" for j in ("coxa", "femur", "tibia") if f"{target}_{j}" in servos)
        desc = f"Single Leg '{target}' (3 servos)"
    elif target in ("left", "right"):
        active_sids.update(s.id for s in servos.values() if s.board == target)
        desc = f"{target.capitalize()} Board (6 servos)"
    else:
        active_sids.update(servos.keys())
        desc = "All 12 Servos"

    driver.release_all()
    print(f"\n---> Commanding Stand Pose on {desc} (height={cfg['gait']['height_stand']} mm)...")
    g = cfg["geometry"]
    kin = LegKinematics(g["coxa"], g["femur"], g["tibia"])
    gait = GaitEngine(cfg)
    feet = gait.nominal(cfg["gait"]["height_stand"])

    targets = {}
    for leg, (x, y, z) in feet.items():
        th1, a, b, ok = kin.ik_deg(x, y, z)
        targets[f"{leg}_coxa"] = th1
        targets[f"{leg}_femur"] = a
        targets[f"{leg}_tibia"] = b

    for sid in active_sids:
        us = servos[sid].deg_to_us(targets[sid])
        driver.set_pulse(servos[sid].channel, us, board=servos[sid].board)
        time.sleep(0.04)
    print(f"     [OK] In Stand Pose. Holding for {duration_s} seconds...")
    time.sleep(duration_s)
    driver.release_all()
    print("     Released.")


def run_gait_test(driver, cfg, servos, mode="crawl", cmd=(0.6, 0.0, 0.0), duration_s=6.0, target=None):
    """Run real walking gait test directly in terminal.
    Can run on an INDIVIDUAL SERVO, a SINGLE LEG, a SINGLE BOARD, or ALL SERVOS.
    Unselected servos are completely released/unpowered (0mA current draw).
    """
    g = cfg["geometry"]
    kin = LegKinematics(g["coxa"], g["femur"], g["tibia"])
    gait = GaitEngine(cfg)

    # Resolve active servos
    active_sids = set()
    if target in servos:
        active_sids.add(target)
        desc = f"Single Servo '{target}' (1 servo active, low-power safe)"
    elif target in ("FL", "FR", "RL", "RR"):
        active_sids.update(f"{target}_{j}" for j in ("coxa", "femur", "tibia") if f"{target}_{j}" in servos)
        desc = f"Single Leg '{target}' (3 servos active, low-power safe)"
    elif target in ("left", "right"):
        active_sids.update(s.id for s in servos.values() if s.board == target)
        desc = f"{target.capitalize()} Board ({len(active_sids)} servos active)"
    else:
        active_sids.update(servos.keys())
        desc = f"All 12 Servos ({len(active_sids)} active)"

    # Release everything first so only target receives pulses
    driver.release_all()

    print(f"\n---> Running Gait Test: {mode.upper()} with cmd={cmd}")
    print(f"     Target: {desc} | Duration: {duration_s}s...")
    
    t0 = time.monotonic()
    dt = 0.02
    last_print = 0.0
    while time.monotonic() - t0 < duration_s:
        t_start = time.perf_counter()
        feet = gait.update(dt, mode, cmd)
        for leg, (x, y, z) in feet.items():
            th1, a, b, ok = kin.ik_deg(x, y, z)
            leg_targets = {
                f"{leg}_coxa": th1,
                f"{leg}_femur": a,
                f"{leg}_tibia": b
            }
            for sid in active_sids:
                if sid in leg_targets:
                    driver.set_pulse(servos[sid].channel, servos[sid].deg_to_us(leg_targets[sid]), board=servos[sid].board)
        
        elapsed = time.monotonic() - t0
        if elapsed - last_print > 1.0:
            last_print = elapsed
            print(f"     Walking... {elapsed:.1f}s / {duration_s}s | Active: {len(active_sids)} servos | Swing: {gait.swing}")
        
        took = time.perf_counter() - t_start
        if took < dt:
            time.sleep(dt - took)
    driver.release_all()
    print("     Gait test complete & all servos released.")


def interactive_menu(cfg, driver, servos):
    while True:
        print("\n" + "=" * 60)
        print("          QUADBOT HARDWARE & GAIT DIAGNOSTIC MENU")
        print("=" * 60)
        print("  1. I2C Bus Scan (Check 0x40 & 0x50)")
        print("  2. Test Single Servo Jog (Cycle through joints)")
        print("  3. Test Single Leg Jog (FL, FR, RL, RR)")
        print("  4. GAIT WALK TEST: Single Servo (Only 1 servo powered!)")
        print("  5. GAIT WALK TEST: Single Leg (Only 3 servos powered!)")
        print("  6. GAIT WALK TEST: Single Board (6 servos: Left or Right)")
        print("  7. Stand Pose Test (Single Leg or All)")
        print("  8. Soft Center All 12 Servos (1500 µs)")
        print("  9. Release All Servos (Limp / Safe)")
        print(" 10. Full 12-Servo Crawl Walk Test")
        print(" 11. Full 12-Servo Turn Test")
        print(" 12. Hardware Jitter Troubleshooting Guide")
        print("  0. Exit")
        print("=" * 60)

        choice = input("Enter choice (0-12): ").strip()
        if choice == "1":
            found = scan_i2c_bus(1)
            print_i2c_report(found)
        elif choice == "2":
            print("\nAvailable servos:")
            s_list = list(servos.keys())
            for i, sid in enumerate(s_list):
                print(f"  {i + 1:2d}. {sid} ({servos[sid].board}, ch {servos[sid].channel})")
            sel = input("Pick a servo number or id: ").strip()
            sid = None
            if sel.isdigit() and 1 <= int(sel) <= len(s_list):
                sid = s_list[int(sel) - 1]
            elif sel in servos:
                sid = sel
            if sid:
                test_single_servo(driver, servos[sid])
            else:
                print("Invalid servo selection.")
        elif choice == "3":
            leg = input("Enter leg (FL, FR, RL, RR): ").strip().upper()
            if leg in ("FL", "FR", "RL", "RR"):
                for j in ("coxa", "femur", "tibia"):
                    sid = f"{leg}_{j}"
                    test_single_servo(driver, servos[sid], duration_s=1.5)
            else:
                print("Invalid leg name.")
        elif choice == "4":
            print("\nSelect servo to test gait on (ONLY this servo will move):")
            s_list = list(servos.keys())
            for i, sid in enumerate(s_list):
                print(f"  {i + 1:2d}. {sid}")
            sel = input("Pick servo number or id: ").strip()
            sid = s_list[int(sel) - 1] if sel.isdigit() and 1 <= int(sel) <= len(s_list) else sel
            if sid in servos:
                run_gait_test(driver, cfg, servos, mode="crawl", cmd=(0.6, 0.0, 0.0), duration_s=5.0, target=sid)
            else:
                print("Invalid servo.")
        elif choice == "5":
            leg = input("Enter leg to test gait (FL, FR, RL, RR): ").strip().upper()
            if leg in ("FL", "FR", "RL", "RR"):
                run_gait_test(driver, cfg, servos, mode="crawl", cmd=(0.6, 0.0, 0.0), duration_s=5.0, target=leg)
            else:
                print("Invalid leg name.")
        elif choice == "6":
            b = input("Enter board to test (left or right): ").strip().lower()
            if b in ("left", "right"):
                run_gait_test(driver, cfg, servos, mode="crawl", cmd=(0.6, 0.0, 0.0), duration_s=5.0, target=b)
            else:
                print("Invalid board name.")
        elif choice == "7":
            leg = input("Enter leg for stand pose (FL, FR, RL, RR or 'all'): ").strip().upper()
            target = leg if leg in ("FL", "FR", "RL", "RR") else None
            test_stand_pose(driver, cfg, servos, duration_s=4.0, target=target)
        elif choice == "8":
            soft_center_all(driver, servos)
        elif choice == "9":
            driver.release_all()
            print("All servos released (limp).")
        elif choice == "10":
            run_gait_test(driver, cfg, servos, mode="crawl", cmd=(0.6, 0.0, 0.0), duration_s=5.0)
        elif choice == "11":
            run_gait_test(driver, cfg, servos, mode="crawl", cmd=(0.0, 0.0, 0.8), duration_s=5.0)
        elif choice == "12":
            print_jitter_guide()
        elif choice == "0":
            driver.release_all()
            print("Exiting diagnostics.")
            break
        else:
            print("Invalid option.")


def print_jitter_guide():
    print("\n" + "=" * 65)
    print("      SERVO JITTER & VOLTAGE BROWNOUT TROUBLESHOOTING GUIDE")
    print("=" * 65)
    print("""
1. COMMON GROUND (Most Common Cause of Jitter):
   - The PCA9685 GND MUST be tied to the Raspberry Pi GND (Pin 6).
   - The Servo Power Supply GND MUST also be connected to the SAME GND.
   - If servo GND and Pi GND are separate, the PWM signal reference floats,
     causing rapid, violent servo chatter/twitching!

2. POWER SUPPLY CURRENT CAPACITY:
   - 12 MG958 / MG996R / MG995 servos draw 1.0A - 2.5A peak stall EACH.
   - Total peak current can reach 10A - 15A during sudden moves!
   - If using a battery or BEC, it MUST be capable of at least 8A - 10A @ 5V-6V.
   - If your power supply drops below 4.5V, the servo internal microcontroller
     browns out and resets continuously (sounds like clicking/buzzing).

3. TESTING WITH LOW POWER:
   - Use 'python -m quadbot.diag --gait-leg FL' to test 1 leg (only 3 servos).
   - Use 'python -m quadbot.diag --gait-servo FL_femur' to test 1 joint.
   - This lets you verify gaits and kinematics even with a 2A bench supply!

4. LOGIC VOLTAGE vs SERVO VOLTAGE:
   - PCA9685 VCC (logic): Connect to Pi 3.3V (Pin 1).
   - PCA9685 V+ (screw terminal): Connect to external 5V-6V battery/BEC.
   - NEVER connect 5V-6V to the PCA9685 VCC pin (it can back-feed the Pi 3.3V rail).

5. SOLDER JUMPERS:
   - Left PCA9685: 0x50 (bridge A4 pads).
   - Right PCA9685: 0x40 (default, no solder jumpers).
""")
    print("=" * 65)


def main():
    ap = argparse.ArgumentParser(description="Quadbot Hardware Diagnostic & Gait Testing Tool")
    ap.add_argument("--config", default=str(ROOT / "config" / "robot.yaml"))
    ap.add_argument("--scan", action="store_true", help="Scan I2C bus for 0x40 and 0x50")
    ap.add_argument("--test-servo", help="Test a single servo jog (e.g. FL_coxa)")
    ap.add_argument("--test-leg", help="Test a single leg jog (FL, FR, RL, RR)")
    ap.add_argument("--gait-servo", help="Run crawl gait on a SINGLE SERVO ONLY (e.g. FL_femur)")
    ap.add_argument("--gait-leg", help="Run crawl gait on a SINGLE LEG ONLY (FL, FR, RL, RR)")
    ap.add_argument("--gait-board", help="Run crawl gait on ONE BOARD ONLY (left or right)")
    ap.add_argument("--stand-leg", help="Hold stand pose on ONE LEG ONLY (FL, FR, RL, RR)")
    ap.add_argument("--all-1500", action="store_true", help="Soft-center all servos to 1500 us")
    ap.add_argument("--stand", action="store_true", help="Hold stand pose on all legs")
    ap.add_argument("--crawl", action="store_true", help="Run crawl forward gait test on all legs")
    ap.add_argument("--turn", action="store_true", help="Run turn in place gait test on all legs")
    ap.add_argument("--release", action="store_true", help="Release all servos")
    ap.add_argument("--jitter-guide", action="store_true", help="Print jitter troubleshooting guide")
    args = ap.parse_args()

    cfg = cfgmod.load(args.config)
    from .servos import ServoCal
    servos = {s["id"]: ServoCal.from_dict(s) for s in cfg["servos"]}
    for sid, s in servos.items():
        if not s.board or s.board == "default":
            s.board = "left" if s.leg in ("FL", "RL") else "right"

    if args.jitter_guide:
        print_jitter_guide()
        return

    if args.scan:
        found = scan_i2c_bus(1)
        print_i2c_report(found)
        return

    try:
        driver = make_driver(cfg)
    except Exception as e:
        print(f"[!] Could not initialize driver: {e}")
        print("    Running I2C bus scan to diagnose...")
        scan_i2c_bus(1)
        return

    try:
        if args.release:
            driver.release_all()
            print("All servos released.")
        elif args.gait_servo:
            if args.gait_servo in servos:
                run_gait_test(driver, cfg, servos, mode="crawl", cmd=(0.6, 0.0, 0.0), duration_s=5.0, target=args.gait_servo)
            else:
                print(f"Unknown servo '{args.gait_servo}'. Valid: {list(servos.keys())}")
        elif args.gait_leg:
            leg = args.gait_leg.upper()
            if leg in ("FL", "FR", "RL", "RR"):
                run_gait_test(driver, cfg, servos, mode="crawl", cmd=(0.6, 0.0, 0.0), duration_s=5.0, target=leg)
            else:
                print(f"Invalid leg '{args.gait_leg}'. Valid: FL, FR, RL, RR")
        elif args.gait_board:
            b = args.gait_board.lower()
            if b in ("left", "right"):
                run_gait_test(driver, cfg, servos, mode="crawl", cmd=(0.6, 0.0, 0.0), duration_s=5.0, target=b)
            else:
                print(f"Invalid board '{args.gait_board}'. Valid: left, right")
        elif args.stand_leg:
            leg = args.stand_leg.upper()
            if leg in ("FL", "FR", "RL", "RR"):
                test_stand_pose(driver, cfg, servos, duration_s=4.0, target=leg)
            else:
                print(f"Invalid leg '{args.stand_leg}'. Valid: FL, FR, RL, RR")
        elif args.test_servo:
            if args.test_servo in servos:
                test_single_servo(driver, servos[args.test_servo])
            else:
                print(f"Unknown servo '{args.test_servo}'. Valid: {list(servos.keys())}")
        elif args.test_leg:
            leg = args.test_leg.upper()
            for j in ("coxa", "femur", "tibia"):
                sid = f"{leg}_{j}"
                if sid in servos:
                    test_single_servo(driver, servos[sid], duration_s=1.5)
        elif args.all_1500:
            soft_center_all(driver, servos)
        elif args.stand:
            test_stand_pose(driver, cfg, servos)
        elif args.crawl:
            run_gait_test(driver, cfg, servos, mode="crawl", cmd=(0.6, 0.0, 0.0), duration_s=5.0)
        elif args.turn:
            run_gait_test(driver, cfg, servos, mode="crawl", cmd=(0.0, 0.0, 0.8), duration_s=5.0)
        else:
            interactive_menu(cfg, driver, servos)
    finally:
        driver.close()


if __name__ == "__main__":
    main()

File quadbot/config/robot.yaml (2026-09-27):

driver: pca9685
pca9685:
  stagger: true
  boards:
    left: {bus: 1, address: 80, freq_hz: 50, osc_hz: 25000000, stagger: true}
    right: {bus: 1, address: 64, freq_hz: 50, osc_hz: 25000000, stagger: true}
lidar:
  driver: mock
  port: /dev/ttyUSB0
  baud: 115200
  clockwise: true
  mount_offset_deg: 0
  mask_deg: []
battery: {enabled: true, driver: ads1115, bus: 1, address: 72, channel: 0, divider_ratio: 5.0,
  v_min: 6.6, v_max: 8.4, v_warn: 7.0}
control: {rate_hz: 50, command_timeout_s: 0.4, pulse_abs_min: 500, pulse_abs_max: 2500,
  sweep_rate_us_s: 200, jog_rate_us_s: 600}
geometry: {coxa: 45, femur: 80, tibia: 131}
legs:
  FL:
    hip_xy: [90, 60]
    side: 1
    gamma: 45
  FR:
    hip_xy: [90, -60]
    side: -1
    gamma: -45
  RL:
    hip_xy: [-90, 60]
    side: 1
    gamma: 135
  RR:
    hip_xy: [-90, -60]
    side: -1
    gamma: -135
gait: {height_stand: 97.0, height_rest: 46.0, stance_reach: 116.0, step_len: 35.0,
  stride_scale: 2.0, step_speed: 1.5, coxa_gain: 1.5, step_height: 35.0, lift_scale: 2.0,
  yaw_step_deg: 20.0, turn_scale: 0.8, freq_hz: 1.35, speed_scale: 1.5, duty_crawl: 0.75,
  duty_trot: 0.5}
avoid: {enabled: true, stop_mm: 350, slow_mm: 900, arc_deg: 35, min_range_mm: 120,
  turn_gain: 0.8, max_age_s: 0.6}
servos:
- {id: FL_coxa, leg: FL, joint: coxa, model: MG958, channel: 3, us_min: 500, us_max: 2500,
  us_center: 1500, us_per_deg: 11.11, invert: true, max_speed_dps: 70, deg_min: -90.0,
  deg_max: 90.0, board: right}
- {id: FL_femur, leg: FL, joint: femur, model: MG958, channel: 4, us_min: 620, us_max: 2500.0,
  us_center: 2039.0, us_per_deg: 9.78, invert: true, max_speed_dps: 100, deg_min: -90.0,
  deg_max: 90.0, board: right}
- {id: FL_tibia, leg: FL, joint: tibia, model: MG958, channel: 5, us_min: 717.0, us_max: 2477.0,
  us_center: 1589.0, us_per_deg: 9.78, invert: true, max_speed_dps: 100, deg_min: -90.0,
  deg_max: 90.0, board: right}
- {id: RL_coxa, leg: RL, joint: coxa, model: MG958, channel: 0, us_min: 500, us_max: 2500,
  us_center: 1500, us_per_deg: 11.11, invert: true, max_speed_dps: 70, deg_min: -90.0,
  deg_max: 90.0, board: right}
- {id: RL_femur, leg: RL, joint: femur, model: MG995, channel: 1, us_min: 832.0, us_max: 2500.0,
  us_center: 2122.0, us_per_deg: 10.0, invert: true, max_speed_dps: 100, deg_min: -90.0,
  deg_max: 90.0, board: right}
- {id: RL_tibia, leg: RL, joint: tibia, model: MG995, channel: 2, us_min: 547.0, us_max: 2500.0,
  us_center: 1485.0, us_per_deg: 10.0, invert: true, max_speed_dps: 100, deg_min: -90.0,
  deg_max: 90.0, board: right}
- {id: FR_coxa, leg: FR, joint: coxa, model: MG958, channel: 3, us_min: 500, us_max: 2500,
  us_center: 1500, us_per_deg: 11.11, invert: false, max_speed_dps: 70, deg_min: -90.0,
  deg_max: 90.0, board: left}
- {id: FR_femur, leg: FR, joint: femur, model: MG996R, channel: 4, us_min: 715.0,
  us_max: 2484.0, us_center: 1938.0, us_per_deg: 9.78, invert: true, max_speed_dps: 100,
  deg_min: -90.0, deg_max: 90.0, board: left}
- {id: FR_tibia, leg: FR, joint: tibia, model: MG996R, channel: 5, us_min: 722.0,
  us_max: 2500.0, us_center: 1596.0, us_per_deg: 9.78, invert: true, max_speed_dps: 100,
  deg_min: -90.0, deg_max: 90.0, board: left}
- {id: RR_coxa, leg: RR, joint: coxa, model: MG958, channel: 0, us_min: 500, us_max: 2500,
  us_center: 1500, us_per_deg: 11.11, invert: false, max_speed_dps: 70, deg_min: -90.0,
  deg_max: 90.0, board: left}
- {id: RR_femur, leg: RR, joint: femur, model: MG996R, channel: 1, us_min: 731.0,
  us_max: 2500, us_center: 2063.0, us_per_deg: 11.11, invert: true, max_speed_dps: 100,
  deg_min: -90.0, deg_max: 90.0, board: left}
- {id: RR_tibia, leg: RR, joint: tibia, model: MG996R, channel: 2, us_min: 601.0,
  us_max: 2486.0, us_center: 1582.0, us_per_deg: 8.33, invert: true, max_speed_dps: 100,
  deg_min: -90.0, deg_max: 90.0, board: left}

imu:
  enabled: true
  bus: 1
  address: 0x68
  rate_hz: 100
  filter_alpha: 0.98
  stabilize: false
  max_correction_mm: 8.0
  deadband_deg: 1.8
  pid:
    kp: 0.35
    ki: 0.0
    kd: 0.015
    integral_limit: 4.0
  axis_map:
    forward: [x, 1]
    left: [y, 1]
    up: [z, 1]
  offsets:
    roll_deg: 0.0
    pitch_deg: 0.0

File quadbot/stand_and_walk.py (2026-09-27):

#!/usr/bin/env python3
"""
Power-Efficient Stand, Hold Still, & 2-Leg Trot Gait Walk Script
================================================================
Hardware Mapping:
- Left Board  (I2C: 0x50, Bus: 1): Front-Left (FL) and Rear-Left (RL)
- Right Board (I2C: 0x40, Bus: 1): Front-Right (FR) and Rear-Right (RR)
- Battery ADC (I2C: 0x48, Bus: 1): ADS1115 2S LiPo monitor (AIN0, 5:1 divider)

Locomotion Sequence:
1. Soft Stand-Up: Cosine S-curve gentle ramp from rest to nominal stance (prevents current inrush).
2. Hold Still: Holds stable stance for 2.5 seconds (confirms posture & balance).
3. 2-Legs-at-a-Time Forward Walk: Synchronized diagonal trot gait for 5.0 seconds
   - Pair A (FL + RR): swings forward while Pair B supports body in stance.
   - Pair B (FR + RL): swings forward while Pair A supports body in stance.
4. Power-Saving Shutdown: Eases back to center and immediately cuts PWM power (limp mode)
   dropping idle current draw to 0.00A.

Usage:
  python stand_and_walk.py                    # Standard 5-second walk with 2.5s hold
  python stand_and_walk.py --duration 7.0     # Walk for 7 seconds
  python stand_and_walk.py --hold 3.0         # Hold still for 3 seconds before walking
  python stand_and_walk.py --speed normal     # Use normal speed instead of slow
  python stand_and_walk.py --scan             # Scan I2C bus and unlock boards
  python stand_and_walk.py --battery          # Read 2S battery status
  python stand_and_walk.py --release          # Cut power to all servos immediately
"""

import sys
import time
import math
import argparse
import atexit
import signal

# ==============================================================================
# HARDWARE CONFIGURATION & CALIBRATED LIMITS
# ==============================================================================

BOARDS = {
    "left":  {"bus": 1, "address": 0x50},  # Front-Right & Rear-Right
    "right": {"bus": 1, "address": 0x40},  # Front-Left & Rear-Left
}

# Calibrated limits from Servo Calibration (2).xlsx / robot.yaml
SERVOS = {
    # Right Board (0x40): FL (ch 3,4,5) and RL (ch 0,1,2)
    "FL_coxa":  {"board": "right", "ch": 3, "model": "MG958",  "min": 500, "max": 2500, "center": 1500},
    "FL_femur": {"board": "right", "ch": 4, "model": "MG958",  "min": 620, "max": 2500, "center": 2039},
    "FL_tibia": {"board": "right", "ch": 5, "model": "MG958",  "min": 717, "max": 2477, "center": 1589},

    "RL_coxa":  {"board": "right", "ch": 0, "model": "MG958",  "min": 500, "max": 2500, "center": 1500},
    "RL_femur": {"board": "right", "ch": 1, "model": "MG995",  "min": 832, "max": 2500, "center": 2122},
    "RL_tibia": {"board": "right", "ch": 2, "model": "MG995",  "min": 547, "max": 2500, "center": 1485},

    # Left Board (0x50): FR (ch 3,4,5) and RR (ch 0,1,2)
    "FR_coxa":  {"board": "left",  "ch": 3, "model": "MG958",  "min": 500, "max": 2500, "center": 1500},
    "FR_femur": {"board": "left",  "ch": 4, "model": "MG996R", "min": 715, "max": 2484, "center": 1938},
    "FR_tibia": {"board": "left",  "ch": 5, "model": "MG996R", "min": 722, "max": 2500, "center": 1596},

    "RR_coxa":  {"board": "left",  "ch": 0, "model": "MG958",  "min": 500, "max": 2500, "center": 1500},
    "RR_femur": {"board": "left",  "ch": 1, "model": "MG996R", "min": 731, "max": 2500, "center": 2063},
    "RR_tibia": {"board": "left",  "ch": 2, "model": "MG996R", "min": 601, "max": 2486, "center": 1582},
}

# Diagonal pairs for 2-leg locomotion (Trot Gait)
PAIR_A = ["FL", "RR"]  # Front-Left + Rear-Right
PAIR_B = ["FR", "RL"]  # Front-Right + Rear-Left

# Power-saving motion presets
SPEED_PRESETS = {
    "slow": {
        "name": "Slow & Power Efficient",
        "cycle_period_s": 1.5,      # Calm cadence prevents back-EMF & dynamic current spikes
        "coxa_swing_amp": 55.0,     # Damped coxa amplitude for digital servos (low inertia)
        "femur_lift_amp": 85.0,     # Ground clearance without high vertical work
        "tibia_fold_amp": 70.0,     # Smooth foot tuck
        "stand_ramp_s": 1.8,        # Smooth S-curve stand up
    },
    "normal": {
        "name": "Normal Dynamic Trot",
        "cycle_period_s": 1.2,
        "coxa_swing_amp": 75.0,
        "femur_lift_amp": 100.0,
        "tibia_fold_amp": 85.0,
        "stand_ramp_s": 1.4,
    }
}

PCA_MODE1     = 0x00
PCA_MODE2     = 0x01
PCA_PRESCALE  = 0xFE
PCA_LED0_ON_L = 0x06
PCA_ALL_ON_H  = 0xFB
PCA_ALL_OFF_H = 0xFD

# State tracking to guarantee zero-velocity starts
CURRENT_US = {sid: 1500.0 for sid in SERVOS}


# ==============================================================================
# HARDWARE DRIVER
# ==============================================================================

def scan_i2c_bus(smbus, max_addr=0x77):
    found = []
    for addr in range(0x03, max_addr + 1):
        try:
            smbus.write_quick(addr)
            found.append(addr)
        except Exception:
            try:
                smbus.read_byte(addr)
                found.append(addr)
            except Exception:
                pass
    return found
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

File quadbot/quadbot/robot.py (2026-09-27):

"""The robot controller: one place that owns safety state, modes and the control tick.

Safety rules, in order of importance:
  * Nothing moves until the robot is ARMED, and a servo only gets pulses once you
    enable that individual servo. Disabled servos are released (limp).
  * E-stop and disarm release every channel immediately.
  * No fresh drive command for `command_timeout_s` -> the drive command falls to zero.
  * Pulses are clamped to each servo's calibrated hard limits and speed-limited.
"""
import math
import time
from dataclasses import asdict

from . import avoid as avoidmod
from .battery import make_battery_reader
from .config import save as save_cfg
from .gait import GaitEngine, GAITS
from .imu import MPU6050
from .kinematics import LegKinematics
from .pid import PID
from .poses import PoseActionEngine
from .servos import AutoDerate, ServoCal, SlewLimiter

MODES = ("calib", "legtest", "rest", "stand", "crawl", "trot", "pace", "bound", "pronk", "wave", "dance")
ACTIONS = ("wave", "dance", "crab", "pushup", "bow", "wiggle", "stretch", "peek", "shake")
CAL_FIELDS = ("channel", "board", "us_per_deg", "max_speed_dps", "deg_min", "deg_max")


class Robot:
    def __init__(self, cfg, cfg_path, driver, lidar, clock=time.monotonic, battery=None, initial_mode=None):
        self.clock = clock                  # injectable so tests can fast-forward the watchdog
        self.cfg, self.cfg_path = cfg, cfg_path
        self.driver, self.lidar = driver, lidar
        self.battery = battery if battery is not None else make_battery_reader(cfg)
        has_dual = "boards" in cfg.get("pca9685", {})
        for s in cfg.get("servos", []):
            if "board" not in s and has_dual:
                s["board"] = "right" if s.get("leg") in ("FL", "RL") else "left"
        self.servos = {s["id"]: ServoCal.from_dict(s) for s in cfg["servos"]}
        g = cfg["geometry"]
        self.kin = LegKinematics(g["coxa"], g["femur"], g["tibia"])
        self.gait = GaitEngine(cfg)
        self.limiter = SlewLimiter()
        self.derate = AutoDerate()
        self.neutral_deg = self._ik_targets(self.gait.nominal(cfg["gait"]["height_stand"]))
        self.pose_actions = PoseActionEngine(cfg, self.kin, self.neutral_deg, self.servos)
        self.active_action = None
        self.action_phase = 0.0
        self.dance_phase = 0.0
        self.dance_info = {}
        self.wave_phase = None
        self.palm_detected = False
        ic = cfg.get("imu", {})
        self.imu = (
            MPU6050(
                bus_num=ic.get("bus", 1),
                address=ic.get("address", 0x68),
                rate_hz=ic.get("rate_hz", 100),
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

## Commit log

2026-08-13 Intial Commit
    [2 mm pin.stl, 25TServoHorn.f3d, 25TServoHorn.step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]
2026-08-13 Added STL
    [2 mm pin.stl, 25TServoHorn.f3d, 25TServoHorn.step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]
2026-08-20 Added Servo Test
2026-08-20 Added Controller and Sensor list
2026-08-21 Added servo test mapped to esp32
2026-08-23 Added servo calibration data and positioning data
    [Servo Calibration.xlsx]
2026-08-26 Added servo calibration sketches for ESP32 which handles calibration for three servos and has a mode for noting the exact pwm signals
2026-08-28 Updated the calibration data to match the 4 legs
    [Servo Calibration.xlsx]
2026-09-04 Added servo 'READ ME' file
2026-09-04 Servo_test Cleanup
2026-09-13 Added TO-DO list and Fusion files for the upper body of Project Arachnid
    [ElectronicsPlate.f3d, Gimbal_Camera_Mount.f3d, Gimbal_Main_Base.f3d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]
2026-09-22 Add quadbot controller with dual PCA9685 board support
    [robot.yaml]
2026-09-22 Update right PCA9685 board address to 0x50
    [robot.yaml]
2026-09-22 Update README with i2c group permissions
2026-09-22 Fix servo jitter, add auto-enable in walking modes, quick motion debug controls, and diagnostic CLI tool
    [diag.py, robot.py, test_robot.py]
2026-09-22 Support gait testing on individual servos and single legs without power rail collapse
2026-09-22 Add direct per-leg hardware tester script using Servo Calibration v2 limits
2026-09-22 Push latest Servo Calibration v2 spreadsheet and complete quadbot codebase
    [Servo Calibration (2).xlsx]
2026-09-22 Fix dashboard syntax error and add 2S battery monitoring via ADS1115
    [robot.yaml]
2026-09-22 Add Servo Calibration v2 spreadsheet to repository root
    [Servo Calibration (2).xlsx]
2026-09-22 Fix PCA9685 register lockout and configure totem-pole output driver for servos
    [diag.py, test_legs.py]
2026-09-22 Damp coxa speeds, add deadband filtering and smooth S-curve ramping to eliminate coxa jitter
    [robot.yaml]
2026-09-22 Swap PCA9685 board address mapping: Left=0x50, Right=0x40
    [robot.yaml]
2026-09-22 Add power-efficient stand, hold still, and 5s 2-leg trot gait script
2026-09-22 Added the gimbal version 0
    [Gimble_V0.stl]
2026-09-22 Fix gait locomotion activation and eliminate servo signal jitter
    [robot.yaml]
2026-09-23 updated gimbal_V0
    [Gimble_V0.stl]
2026-09-23 trying to fix
    [robot.yaml]
2026-09-23 Added speed
    [robot.yaml]
2026-09-23 updated gaits
    [robot.yaml]
2026-09-24 Updated Config with Gait features
    [robot.yaml]
2026-09-24 updated yaml
    [robot.yaml]
2026-09-24 inverted controls
    [robot.yaml]
2026-09-24 IMU Stabilization with updated robot.yaml
    [robot.yaml]
2026-09-24 IMU Stabilization with updated robot.yaml with real calibration
    [robot.yaml]
2026-09-24 feat(quadbot): add expressive poses, multi-directional dance, and improved wave
    - Add 6-DoF BodyPoseEngine and PoseActionEngine in poses.py supporting
    dynamic body translations and rotations with all feet planted.
    - Implement multi-directional dance mode with continuous figure transitions
    (front-back groove, side-to-side sway, diagonal shifts, and 360 salsa orbit).
    - Upgrade wave action with weight shift to supporting legs and high tibia lift
    off the ground to calibrated bounds.
    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
2026-09-24 feat(nav2): integrate Nav2 stack with Cartographer SLAM, tuned configs and launch files
    [All Pins.3mf, SIde Leg Assembly with Controller Frame.3mf, Side Leg Assembly with Base Plate.3mf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]
2026-09-24 docs: add comprehensive Raspberry Pi getting started guide for Nav2 & SLAM
2026-09-24 feat(quadbot): fix wave tibia direction, tune pushup/wiggle/dance, add crab dance, and improve gamepad & IMU
    - Fix wave tibia lift direction so the tibia lifts up into a high-five salute.
    - Increase ground clearance for push-ups so the robot body never touches the floor.
    - Boost rear coxa rotation amplitude in butt wiggle for more expressive hip motion.
    - Refactor multi-directional dance into an in-place popping/locking breakdance without foot sliding.
    - Add new Crab Dance movement (side-to-side dipping groove).
    - Fix gamepad joystick forward/backward axis inversion (stick forward now moves forward).
    - Redesign gamepad controller mapping with Y button for mode cycling, and face/bumper button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
    [robot.yaml]
2026-09-27 Calibration values
    [robot.yaml]
2026-09-27 feat(quadbot): fix hardware channel mapping, rest posture, dynamic speed, wave weight shift, and add IMU calibration & autostart service
    [robot.yaml]
2026-11-12 Updated Calibration Values
2026-11-12 Implement calibrated FL wave action with balanced weight shift
2026-11-12 feat(lidar): switch to rplidar driver in robot.yaml, add auto port resolution and package dependency
2026-11-13 Add RealSense D435 camera feed, cross-platform PS/Xbox controller remapping, and 180-deg LiDAR inversion
2026-11-13 Fix camera feed streaming, auto-start on boot, V4L2 device ranking, and frontend reconnection
